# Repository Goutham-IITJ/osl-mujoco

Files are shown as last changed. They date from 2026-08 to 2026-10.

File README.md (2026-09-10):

# OSL V2 in MuJoCo

A physics model of the Open-Source Leg V2 (Neurobionics / University of Michigan),
built directly from the official Onshape CAD export and driven from plain Python.
No ROS, no Gazebo, no placeholder geometry.

The point of this repository is to have a trustworthy digital twin *before* the
real hardware is touched, so that motor control, IMU processing and gait-phase
estimation can be developed and broken safely.

Two things live here. The **model** — built from CAD, described from *What you get*
onward — and the **bench experiment**, which drives that model's knee along a real
human's knee-angle trajectory with a PD controller and measures how well it follows.
Start with the experiment; `docs/CODE_MAP.md` is one page and tells you where every
piece of it is.

## Quick Start

Windows PowerShell, from a clean machine. Everything below is run from the repository
root.

**1. Create the two environments.** The bench experiment needs two, and they are
deliberately kept apart — see the table below for why.

```powershell
# the simulation environment: MuJoCo, no plotting
py -3.10 -m venv .venv
.\.venv\Scripts\python.exe -m pip install --upgrade pip
.\.venv\Scripts\python.exe -m pip install mujoco==3.12.0 numpy glfw PyOpenGL

# the analysis environment: plotting, no MuJoCo
py -3.12 -m venv .venv-analysis
.\.venv-analysis\Scripts\python.exe -m pip install --upgrade pip
.\.venv-analysis\Scripts\python.exe -m pip install numpy matplotlib scipy
```

**2. Check that the tests pass.** These need numpy only, so any Python will do, and they
run in under a second:

```powershell
.\.venv\Scripts\python.exe tests\run_tests.py
```

**3. Run the things.** In order of what is most worth seeing first:

```powershell
# the validated AB19 benchmark: 2410 steps, CSV + metrics + figures
.\.venv\Scripts\python.exe experiments\run_bench_ab19.py

# is the result still the validated one?  compares 21 columns + every metric
.\.venv\Scripts\python.exe experiments\verify_against_oracle.py

# the live demo: MuJoCo viewer + a live dashboard in the browser
.\.venv\Scripts\python.exe experiments\run_live_demo.py

# the gain sweep that chose kp = 600
.\.venv\Scripts\python.exe experiments\run_gain_sweep.py

# figures from an already-logged CSV -- this is the one that needs .venv-analysis
.\.venv-analysis\Scripts\python.exe experiments\plot_bench_results.py
```

`run_bench_ab19.py` also draws the figures itself if matplotlib happens to be importable;
in `.venv` it is not, so it writes the CSV, prints the report, and tells you to run
`plot_bench_results.py`. Use `--no-plot` to silence that.

**Where the output goes.** Everything lands under `build\`, which is gitignored:

| Path | Written by | Contents |
| --- | --- | --- |
| `build\bench_track_ab19\bench_track_ab19.csv` | `run_bench_ab19.py` | 2410 rows × 21 columns, one row per 0.5 ms step |
| `build\bench_track_ab19\bench_track_ab19_metrics.csv` | `run_bench_ab19.py` | the summary metrics and the 5 audit flags |
| `build\bench_track_ab19\bench_track_ab19.png` | `plot_bench_results.py` | the six-panel results figure |
| `build\bench_track_ab19\bench_track_ab19_human_reference.png` | `plot_bench_results.py` | the human reference figure |
| `build\gain_sweep\` | `run_gain_sweep.py` | the sweep trace and its metrics |
| `build\verify_oracle\` | `verify_against_oracle.py` | the fresh run it compares against the oracle |
| `tests\oracle\` | — | the frozen validated result. **Committed, not generated.** |

**Which environment do I need?** Four exist on this machine and only the first two belong
to this experiment:

| Environment | Python | Holds | Used for |
| --- | --- | --- | --- |
| `osl-mujoco\.venv` | 3.10 | mujoco 3.12.0, numpy, glfw, PyOpenGL — **no matplotlib** | everything that runs physics: the benchmark, the sweep, the live demo, the oracle check, the tests |
| `osl-mujoco\.venv-analysis` | 3.12 | numpy, matplotlib, scipy, h5py — **no mujoco** | offline figures only (`plot_bench_results.py`), and the dataset tooling |
| `myo_folder\.venv-myoassist` | — | MyoAssist + MyoSuite | *not this experiment.* The MyoAssist musculoskeletal work, which is paused. |
| `myo_folder\.venv-myoassist-ctrl` | — | MyoAssist reflex-controller stack | *not this experiment.* Same. |

The split is not tidiness. `.venv` is the environment the validated result was produced in
and it is left alone on purpose, so the physics cannot silently change underneath a
recorded number; matplotlib and scipy pull in a large dependency tree and neither is needed
to step MuJoCo. That is also why plotting is a separate offline entry point reading a CSV
rather than a call at the end of the simulation, and why the live dashboard is a browser
page rather than a matplotlib window.

**The bench experiment needs neither MyoAssist environment, and touches no MyoAssist file.**

## How the bench experiment works

```
   build/AB19_knee_gait_reference.csv
   real human gait data -- subject AB19, one right-leg cycle, 101 samples
                    |
                    v
   +--------------------------------------+
   |  REFERENCE PROCESSING                |   oslbench/reference.py
   |  validate columns, audit, cubic      |   101 samples -> 2410 steps
   |  spline resample onto dt = 0.5 ms    |
   +--------------------------------------+
                    |
                    v
              q_ref(t)   the commanded knee angle, in radians
                    |
                    v
   +--------------------------------------+
   |  PD CONTROLLER                       |   oslbench/controller.py:95
   |                                      |
   |    error = q_ref - q                 |   Kp = 600.0    N.m/rad
   |    tau   = Kp * error - Kd * qdot    |   Kd = 17.253   N.m.s/rad
   +--------------------------------------+
                    |
                    v
   +--------------------------------------+
   |  ACTUATOR SATURATION                 |   two separate clamps
   |  command -> ctrlrange  (the ROM)     |   knee ROM  [-5, 120] deg
   |  torque  -> forcerange (authority)   |   knee tau  +/- 142.2 N.m
   +--------------------------------------+
                    |
                    v
   +--------------------------------------+
   |  MuJoCo ACTUATOR                     |   models/osl_v2_bench.xml
   |  tau = Kp*(ctrl - q) - Kd*qdot,      |   position actuator on the
   |  clamped, applied to the knee hinge  |   knee joint
   +--------------------------------------+
                    |
                    v
   +--------------------------------------+
   |  MuJoCo PHYSICS STEP                 |   mj_step, every 0.5 ms
   |  I_eff = 0.261998 kg.m^2, gravity,   |   fixed base: the segment
   |  joint damping, joint friction       |   above the knee is welded
   +--------------------------------------+
                    |
                    v
              q(t)   the ACTUAL knee angle
                    |
      +-------------+-------------+-------------+
      |             |             |             |
      v             v             v             v
  tracking      actuator        joint       mechanical
   error         torque       velocity        power
 q_ref - q     tau (N.m)     qdot (rad/s)   tau * qdot
      |             |             |             |
      +-------------+------+------+-------------+
                           |
                           v
              +--------------------------+
              |  LOGGER                  |   oslbench/logging.py
              |  one row per step,       |   no physics in here
              |  21 columns              |
              +--------------------------+
                           |
        +------------------+------------------+
        |                  |                  |
        v                  v                  v
   bench_track        METRICS            PLOTS
   _ab19.csv          RMS / peak /       six-panel figure
   2410 rows          torque / lag       drawn AFTER the run
                   oslbench/metrics.py   oslbench/plotting.py
```

Nine things that flowchart is meant to make unambiguous, because each of them is a
question that has actually been asked:

1. **The reference is real human data.** It is not a synthetic sine wave and not an
   idealised curve. It is subject AB19 of the Camargo et al. lower-limb dataset, trial
   `levelground / ccw / normal / 01_01`, one right-leg cycle of 1.2050 s. The audit that
   runs on load prints five flags, and all five concern the dataset's *moment* and *power*
   columns, which are defective and are carried through unused; the angle column that
   drives the experiment is sound.

2. **The controller runs during the simulation.** `error = q_ref - q` and
   `tau = Kp*error - Kd*qdot` are evaluated inside the stepping loop, once per step, at
   2 kHz — using the angle and velocity MuJoCo reported on the previous step. It is not
   pre-computed, and there is no recorded torque being played back.

3. **MuJoCo physics runs every 0.5 ms.** 2410 steps for one gait cycle. That timestep is
   authored in `models/osl_v2_bench.xml` and the experiment reads it rather than assuming
   it; the tests fail if it changes.

4. **The controller is not plotting anything.** `oslbench/controller.py` imports no
   plotting library, writes no file and prints nothing. It is 154 lines and the control law
   is three of them.

5. **The simulation is not generating plots in real time.** `oslbench/simulation.py` has no
   figure in it. The only case where anything is drawn while the physics runs is the live
   demo, and there the drawing is a *consumer* of state that the simulation published — see
   point 7.

6. **The offline plots are generated after the simulation, from the logged CSV.**
   `experiments/plot_bench_results.py` reads `bench_track_ab19.csv` and draws figures. It
   never loads a model and never steps physics — which is why it runs in
   `.venv-analysis`, an environment that has no MuJoCo installed at all. That is a
   structural proof rather than a promise.

7. **The live dashboard is visualisation only and cannot affect the controller.** The
   browser page has no plant model and no controller in it; it polls the simulation loop
   about sixteen times a second for a snapshot of the one shared state and draws it on a
   canvas. Because it redraws in the browser's process it cannot slow the physics, and
   because it has nothing to integrate it cannot become a second simulation. Before the
   viewer opens, `oslbench/viewer.py:consistency_check` replays a span of the quantitative
   benchmark through the live code path and refuses to start unless angle, velocity, torque
   and command agree to 1e-12.

8. **The six-panel figure is generated from recorded simulation results.** Every point on
   it was read out of the CSV that a completed run wrote. It is not a live trace, not a
   sketch, and not measured on hardware.

9. **The physical hardware has not been validated.** Nothing here has been compared against
   the real Open-Source Leg. There is no encoder log, no bench torque measurement and no
   hardware trial. Every number in this repository is a simulation result, and
   `docs/BENCH_EXPERIMENT.md` lists specifically which parts of the model are placeholders.

The validated result, which `verify_against_oracle.py` re-checks column by column:

| RMS error | peak error | peak torque | saturation | peak velocity |
| --- | --- | --- | --- | --- |
| 4.3616° | 9.0907° | 16.0041 N·m (11.25 % of authority) | 0.00 % | 5.0559 rad/s |

90.1 % of that RMS error is a 29.5 ms servo phase lag: remove the shift and the error
falls to 0.4333°. The fix for a lag is feedforward or advancing the reference, not more
stiffness — which is why `kp` stays at 600.

`docs/BENCH_EXPERIMENT.md` is the long form of all of this, in question-and-answer form,
including what the torque is not (it is not a human knee moment) and what the sim-to-real
limitations are. `docs/LIVE_DEMO.md` covers the two-window demo, `docs/VALIDATION.md` the
proof that reorganising the code did not change the result, and
`BENCH_TUNING_AND_DATASET.md` where kp = 600 came from and where the AB19 data came from.

## What you get

Three scenes are generated into `models/`. `osl_v2_bench.xml` welds the leg to the
world, which is the configuration for testing controllers and watching the joints
move without worrying about balance. `osl_v2_ground.xml` gives it a free joint,
puts a floor underneath, and carries collision geometry — the Variflex blade at
the sole, plus one bounding box per module above the ankle — for stance and
loading. The bench and ground scenes both ship a `flat` keyframe that levels the
sole — which is *not* ankle = 0, see the flat-foot finding below — and in the
ground scene it also drops the leg onto the floor. Whether the ground scene stands
or topples has not been established — a single leg with no socket, hip or balance
controller is not obviously stable, though a static check suggests the COM does
project inside the sole footprint with margin. `check_model.py` prints the base
height before and after a second of settling, which answers it.

`osl_v2_walk.xml` is the Phase 2 scaffold: the same CAD device, now hung under a
minimal human model so it can be driven along a walking trajectory. A pelvis is
suspended over the floor — welded, because a prescribed trajectory will drive it
later and there is no balance controller — a residual thigh swings from it on a
`hip` hinge, a socket couples that thigh to the device through four *passive*,
spring-damped DOFs (a vertical piston plus flexion, ab/adduction and rotation —
the compliance a real socket–limb interface has), and the device bolts rigidly
beneath the socket. A second, lumped intact leg swings from the pelvis on its own
hip hinge so the model has two feet on the floor. It ships a `stand` keyframe with
the feet flat and the socket relaxed. Everything above the device — pelvis, thigh,
socket, intact leg — is an anthropometric **placeholder**: not CAD, not fitted,
sized from 50th-percentile tables and meant to be reconciled with the `myoOSL`
human later. See the note under *Simplifications*.

All three scenes carry the same CAD device — the three-body chain knee_prox, shank,
foot, with a knee hinge and an ankle hinge, position actuators on both, and a
sensor suite that mirrors what the real leg reports: joint encoders, actuator
torque, a knee_prox IMU, a shank IMU, and the six-axis load cell. The walk scene
adds hip and contralateral-hip actuators and reports the four passive socket DOFs
as joint-position sensors, so socket travel is observable.

```
python scripts/check_model.py                      # compile, CAD cross-check, contact
python scripts/view_osl.py                         # interactive viewer, bench
python scripts/view_osl.py --scene ground          # viewer with the floor
python scripts/view_osl.py --scene ground --flat   # standing, sole level
python scripts/view_osl.py --scene walk            # device on the walking scaffold
python scripts/view_osl.py --knee 60 --ankle -15   # start in a pose
python scripts/demo_sweep.py                       # sinusoidal knee/ankle sweep
python scripts/demo_sweep.py --headless --csv build/sweep.csv
```

In the viewer, `Tab` opens the control panel where the knee and ankle sliders
live and `space` pauses. The Group toggles hide geom groups: the visual meshes
are group 2, and group 3 is the collision geometry, which exists in the ground and
walk scenes — the blade mesh at the sole, plus the four bounding boxes that stop
the shank and knee_prox reaching the floor, and in the walk scene a box under the
intact foot. The bench scene has no collision geometry at all.

## Model summary

Masses and centres of mass, the latter in **world** coordinates at zero joint
angles (the MJCF stores them body-relative, so the XML numbers will not match
these directly; `check_model.py` prints the world values):

| | mass | COM, world (m) | parts kept | parts culled |
|---|---|---|---|---|
| knee_prox | 0.4498 kg | +0.0002, −0.0074, +0.1997 | 28 | 60 |
| shank | 3.5908 kg | +0.0047, +0.0028, +0.0320 | 142 | 347 |
| foot | 0.9152 kg | −0.0066, −0.0037, −0.1608 | 47 | 26 |
| **total** | **4.9558 kg** | | **217** | **433** |

80 distinct meshes, 1,310,462 triangles. The knee hinge sits at
`(0.00065, 0, 0.19311)` and the ankle at `(0, 0, −0.13873)`, 331.84 mm apart,
both taken from the CAD rather than chosen. Knee range −5° to +120° (positive is
flexion), ankle −30° to +20° (positive is dorsiflexion). Those ranges are from
this export's own hard stops and they differ slightly from the 0–120° and
±30° quoted for "the OSL v2" in Tan et al. 2025; the difference is kept, because
the CAD is the better authority on the specific leg being modelled. Worth
re-measuring on the hardware.

Coordinates are the export's own, so `z = 0` is a point mid-pylon and not a
landmark. The bench-scene bounding box is
`[−0.1665, −0.0437, −0.2302] .. [0.0846, 0.0752, 0.2602]`: 490 mm of build
height from the sole at z = −0.2302 to the top of the proximal pyramid at
z = +0.2602, and 119 mm across. The ankle axis is 91.5 mm above the sole. In the
ground scene everything is lifted so the floor is z = 0, which puts the ankle
axis 93.5 mm above the floor at zero joint angles — 91.5 mm of build height plus
2 mm of spawn clearance, nothing else. The blade really is the lowest thing in
the model (`model_min_z` and the sole's own lowest z are the same −0.2302), and
every bounding box bounds meshes that are already inside that minimum, so there
is no fudge term. The `flat` keyframe sits 3.8 mm lower, at a base height of
0.2284 m, because rotating the sole level tucks the toe up.

Anterior is **−X**, posterior **+X**, and the sagittal plane is XZ. This comes
from the Variflex blade, whose long forefoot runs from the mounting bolts at
x ≈ +0.035 out to x = −0.1665.

## Why the URDF could not simply be loaded

why there is a build step.

The Onshape export (`osl_v2_0_assembly/urdf/`, 682 links, 681 joints, 14,584
lines) has no materials assigned, so every `<inertial>` block is nonsense — the
whole leg weighs 14.75 grams in the file, and 52 of the 657 inertia tensors have
a non-positive eigenvalue (8 of those also violate the triangle inequality that
any real rigid body must satisfy). MuJoCo's URDF reader eigen-decomposes each
inertia tensor while *parsing*, which means `compiler inertiafromgeom="true"`
never gets a chance to help: the load fails before the option is applied.
Sanitising the URDF in place was rejected for the same reason it was tempting —
682 hand-audited blocks is not a reviewable diff.

So `tools/build_mjcf.py` reads the export and emits native MJCF instead. Mass
comes from the exact mesh volume (divergence theorem over each closed triangle
mesh) multiplied by a density assigned per part family, and inertia is computed
about each segment's own COM and then rotated to principal axes. The original
URDF is never modified; everything generated lands in `models/` and `build/`.

Four further things had to be got right, and each was initially got wrong.

**Mesh poses need `<visual><origin>` composed on top of the link pose.** 207 of
the 682 links carry a non-identity visual origin, the largest a 206 mm
translation on the Variflex foot, and ignoring them produces an assembly where
the knee and ankle modules interpenetrate. Folding the origin in reproduces the
export's own declared centre-of-mass positions to a 0.000 mm median and 0.002 mm
at the 90th percentile, against 10.150 mm at the 90th percentile and 158.5 mm at
worst without it; the assembled leg becomes 251 × 119 × 490 mm rather than
211 × 327 × 532 mm, and 327 mm of medio-lateral width on a device under 120 mm
wide is the giveaway. `build/verify/visorigin_AB.png` shows both, and
`tools/verify_visorigin.py` regenerates it.

**Rigid clusters straddling a joint go to the segment opposite the housing.**
The 618 `fixed` joints contract by union-find into clusters, 38 of which carry
geometry, and each is assigned to knee_prox, shank or foot. Nine of the 38 sit
concentric with a hinge axis, where a plain "above or below the joint" split
would be a coin flip. The resolution is mechanical: in a belt-driven actuator the
output pulley rotates *relative to* its housing, and both housings are
shank-fixed, so a cluster concentric with the knee axis belongs to knee_prox and
one concentric with the ankle axis belongs to the foot. That is a 20 mm radius
test in the sagittal plane, applied before the z-split.

**The Össur foot mate is fine.** An earlier pass concluded the mate was corrupt
and reconstructed the foot from anatomical constants; that was an artefact of the
missing visual origin. With the frames right, the foot's length axis is 89.73°
from the ankle axis and the sole is within 2.18° of level — a real build tilt,
deliberately preserved. `_check_foot()` re-verifies this on every build and warns
if it ever stops holding. **The model contains no invented geometry.**

**The floor needed more than a box under the sole, and the sole is not level at
ankle = 0.** The first ground scene put a single tilted box on the sole, fitted to
the blade's bounding box — so its lower face sat 4.6 mm *below* the blade mesh —
and gave nothing above the ankle any collision geometry at all. Commanding the
ankle therefore tipped the leg and the shank sank straight through the floor.
Both halves are fixed. The sole is now a `type="mesh"` geom on the blade itself,
which MuJoCo collides by its convex hull, so the toe spring and the heel roll-off
survive exactly and only the 14 mm arch is bridged — deliberately, since under
load the real blade flattens toward that chord. It shares the visual geom's pose
exactly, because the previous failure mode was the leg standing on something the
viewer does not draw. Above the ankle each module gets one axis-aligned bounding
box: `knee_prox_shell` 78 × 79 × 106 mm, `knee_module` 128 × 119 × 204 mm,
`mid_pylon` 66 × 102 × 69 mm and `ankle_module` 137 × 118 × 192 mm, respectively
21 %, 22 %, 11 % and 20 % full by the volume of the parts they contain. Those
fill fractions are printed so nobody mistakes a box for a shape claim.
Membership comes from the CAD's own named housings — the knee housings span
z = 0.047..0.239 and the ankle housings −0.185..−0.028, disjoint with a 75 mm gap
— rather than from a hand-picked threshold, and the eleven parts that fall
between them are exactly the ones you would name by hand: the pylon, the load
cell, the pyramid and six M5 bolts. Four boxes are enough, and that is checked by
code rather than asserted in a comment: `OslModel.sweep_clearance` walks a 26 × 26
grid of knee −5..120° against ankle −30..+20° and compares the lowest point of
every visual mesh against the lowest point that can actually collide. The answer
comes out twice. Over all 216 visual meshes the worst case is 5.9 mm of clearance;
over the 46 that no box contains — the foot's non-blade hardware, since the foot's
only collision geom is the blade mesh and a mesh bounds nothing — it is 23.6 mm,
at knee = −5°, ankle = −2°, where an M8 socket head hanging off the blade mount is
the binding part. The two differ because a part inside a box on its own body can
never rise above that box, so its clearance only measures how close a rotating box
corner passes to the part that defined it; the second figure is the one with
information in it. Either way no mesh can reach the floor before a collision geom
does. Both numbers are written into the sidecar and `check_model.py:sweep_test`
re-derives both from MuJoCo's own forward kinematics, finding the collidable geoms
by `contype`, the blade by mesh identity and the boxed parts by testing every
vertex in each box's frame, rather than reading any of it from the prediction — so
the CAD sweep and the MuJoCo sweep are two independent measurements of the same
pair of quantities. Both are affordable only because of one shortcut: since every
rotation here is about world Y, the lowest point of a rigid group is the minimum of
a linear functional on the sagittal plane and is therefore always attained at a
vertex of the group's convex hull projected to (x, z), which turns four screw
meshes of 193 k vertices each into a few dozen candidate points for all 676 poses
at once. That is an argument, not a sample, so `sweep_test` redoes each worst pose
with every vertex and fails if the reduced answer differs.
Capsules and z-slabs were both measured and rejected — PCA capsules wanted
r = 81 mm and len = 174 mm on a part whose bounding box is 128 × 119 × 204 mm and
still left 1.0 % of vertices 14.8 mm outside, and 25 mm z-slabs cost 23 geoms to
raise fill from 22 % to 30 %, because the looseness is in x and y where the
batteries hang off, not in z.

And the sole is 2.40° toe-down at ankle = 0, which is the other half of "the leg
falls over when I move the ankle". The dominant edge of the blade's lower convex
hull in the sagittal plane runs 149.5 mm at +2.3971°, from (−0.08936, −0.09146)
to (+0.06001, −0.08521) in the foot frame; the next-longest hull edge is only
34.7 mm, so the contact face is unambiguous by a factor of 4.3. Put the ankle at
+2.3971°, well inside the +20° limit, and the contact becomes a genuine
161 × 64 mm patch: 173 blade vertices within 2 mm of the lowest point, flat to
0.49 mm rms, with a residual tilt of +0.29° sagittal and under 0.01° frontal.
That the frontal residual is negligible is what makes this fixable at all, since
one ankle hinge could never have corrected a frontal tilt. The pose is the `flat`
keyframe in the bench and ground scenes; `view_osl.py --flat` loads it. `build_mjcf.py` derives the
standing height by rotating CAD meshes and `validate_mjcf.py` re-derives it by
rotating the *emitted XML's* collision points about the *emitted* ankle anchor, and
both land on the same +2.00 mm above the floor, which is the spawn clearance and
nothing more. The angle and the edge are still one derivation, though, and would
agree with each other for free — so `check_model.py:flat_test` loads the keyframe
and pushes both endpoints of that edge through MuJoCo's forward kinematics,
requiring them to come out level there too, along with the base height, the set of
collidable geom names and the 2.00 mm clearance itself.

## Simplifications, stated plainly

**Small parts are dropped.** Anything below 0.1 cm³ loses its geometry and has
its mass lumped into the parent segment: 433 of 650 parts, but only 52 g, or
1.05 % of the mass, because they are fasteners, washers and bearing races.
`build/mass_audit.csv` lists every part with its volume, assigned density, the
rule that assigned it, and whether it was kept, sorted by mass. Regenerate it
with `python tools/validate_mjcf.py --audit`.

**The densities are assignments by part family, not measurements.** Aluminium at
2700 covers 245 parts and is the default; steel at 7850 covers 240 fasteners,
bearings and the load cell; electronics at 1500 covers 133 parts of the
Raspberry Pi and its connectors; NdFeB magnets 7500; the Dephy BA30 packs and
the FR-4 PCB 1900; the Variflex blade 1550 as carbon fibre; belts and printed
covers 1250. `tools/cad_findings.py` prints the full usage table.

**The total is 0.42 kg light, and the missing motors account for it.** The model
comes out at 4.9558 kg against a published 5.377 kg for a real OSL V2 build
(Tan et al., *MyoAssist 0.1*, ICORR 2025, which cites Best et al. 2024 and
Azocar et al. 2018; Elliott Rouse, who runs the OSL project, is a co-author).
The reason is that **the Onshape export contains no motors.** All 260 distinct
meshes were searched: the only motor-related part is `p_b0004_motorCoupling.stl`
at 8.8 g, present twice — the couplings that bolt *to* the motors. There is no
rotor, no stator, no gearbox and no Dephy actuator body anywhere in the export.
The 0.4212 kg shortfall is 0.2106 kg per motor, which is the right order for a
brushless motor of this class.

That is a hypothesis, and the way to settle it is to put a motor on a scale.
`MOTOR_MASS` in `build_mjcf.py` will lump a measured per-motor mass at each
coupling centroid, and **it defaults to zero on purpose**: inferring the motor
mass from (published − ours) and then citing the resulting agreement as
validation would be circular. The 4.9558 kg figure has to stand on its own, so
the shipped model stays purely CAD-derived.

An earlier version of this file claimed the opposite — that the model was too
*heavy*, against a 3.0–4.5 kg range. That range was recollection with no source
behind it and it was wrong. `MASS_RANGE` is now 4.70–5.20 kg, the window the
CAD-only total should land in given two absent motors. It governs the **device**,
so in the walk scene the validator range-checks the device mass alone and ignores
the scaffold; by that measure all three scenes sit inside it.

**The walk scene's human scaffold is a placeholder, not a measurement.** The
pelvis (10 kg), residual thigh (3.5 kg, 0.20 m), socket (0.6 kg) and lumped intact
leg (~12 kg) are anthropometric round numbers — 50th-percentile segment masses and
lengths of the kind tabulated in Winter's *Biomechanics and Motor Control* — with
capsule and box geometry that carries `contype=0`, so none of it collides with
anything except through the box under the intact foot. The four socket DOFs have
hand-set stiffness and damping standing in for a socket–limb compliance that has
not been characterised. None of this is CAD and none of it is fitted: it exists so
the CAD device has a hip to hang from and two feet to stand on while a walking
trajectory is developed, and it is meant to be replaced by — or reconciled
against — the `myoOSL` musculoskeletal human in MyoAssist. The hip height is not
chosen but derived (unloaded leg length below a welded pelvis), so the device sole
sits 2 mm above the floor at the default pose, exactly as the ground scene lifts
the free leg.

**Everything inside the actuators is collapsed.** Belts, pulleys, gearboxes and
bearings contribute mass and geometry but no relative motion; the knee and ankle
are single hinges with lumped `armature`, `damping` and `frictionloss` standing
in for the transmission. Those numbers (armature 0.010 and 0.008 kg·m², damping
0.30 and 0.25 N·m·s, friction 0.40 and 0.30 N·m) are placeholders to be
identified from bench data, not derived quantities. Peak torque is *not* a
placeholder: the actuator `forcerange` is ±142.2 N·m at the knee and
±168.2 N·m at the ankle, the published figures from the same paper as the mass.
The position-servo gain `kp = 60` is a placeholder and a soft one — it will not
hold a limb under body weight and is expected to change as soon as the model is
loaded.

**Contact is faithful at the sole and coarse everywhere else.** The sole is the
blade's own mesh, collided by its convex hull, which is honest geometry. Above it
are four bounding boxes at roughly 20 % fill, whose only job is to keep the leg
out of the floor; any result that depends on *where* the shank or the knee touches
something is not yet meaningful. There is no self-collision model either —
MuJoCo's `filterparent` removes knee_prox↔shank and shank↔foot automatically, and
knee_prox↔foot was shown unreachable across the joint ranges rather than modelled.

**Contact timing is set, contact depth is measured rather than predicted.** Both
scenes now write `solref="0.002 1"` and `solimp="0.95 0.99 0.001 0.5 2"` instead
of inheriting the compiler defaults. The argument is about time, since that is
what `solref[0]` specifies: the default 0.02 s time constant is 40× the 0.5 ms
timestep and slower than the 10 ms scale on which heel strike, foot flat and toe
off resolve, so it would smear exactly the transitions an impedance controller
switches on. 0.002 s puts the contact an order of magnitude faster than the
control events, and is deliberately 4× the timestep rather than sitting on
MuJoCo's `timeconst >= 2 * timestep` stability floor. Resting penetration scales
as the square of that constant, so the change is worth about 100× — but the
absolute depth is **not** predicted anywhere in this repo, because the
coefficient depends on how the `solimp` impedance enters the solver's
regularisation and `check_model.py` can read `contact.dist` and simply measure
it. What is asserted is a bound: 0.5 mm, chosen against the 0.49 mm rms flatness
of the contact patch, past which the sole sinking starts to matter next to the
shape of the sole itself. One trap worth knowing, and the reason the floor plane
and the leg's collision geoms share a single `contact` default class: MuJoCo does
not take the stiffer of two touching geoms, it averages `solref` and `solimp`
between them, so a floor left at the default would have quietly given back most
of the benefit. `validate_mjcf.py` resolves the default-class chain of every
collidable geom and fails if they ever disagree.

## Layout

`tools/oslcad.py` is the geometry layer — STL reading, exact mesh mass
properties, the URDF graph, rigid-cluster contraction, density rules.
`tools/build_mjcf.py` turns that into the three MJCF scenes and is where every
measured constant lives. Alongside each scene it writes
`models/osl_v2_<scene>.pred.json`: the masses, world centres of mass, hinge
anchors and mesh bounding box it expects MuJoCo to report, so that
`check_model.py` can hold MuJoCo to the CAD instead of merely asking whether it
compiled.
`tools/validate_mjcf.py` re-implements MuJoCo's compile checks in pure Python so
the model can be verified without MuJoCo installed; all three scenes currently pass
clean — 1767, 1815 and 1979 checks with no warnings. It also independently re-derives
the `flat` keyframe from the emitted XML, because a keyframe whose whole purpose is
"stand the leg level on the floor" is exactly the kind of claim that can be
silently false — the sole geometry it replaced sat 4.6 mm below the mesh it was
meant to hug and nothing noticed.
`tools/cad_findings.py` re-derives every geometric claim with its evidence and is
what `docs/CAD_FINDINGS.md` contains.
`tools/softrender.py` is a dependency-free rasteriser; `tools/verify_visorigin.py`
and `tools/render_poses.py` use it to regenerate the two evidence images.
`render_poses.py` reads the *generated* MJCF and steps it through seven
knee/ankle poses, which catches the class of error a compile check cannot: a
segment on the wrong body, a flipped axis, a misplaced hinge.

`scripts/check_model.py`, `scripts/view_osl.py` and `scripts/demo_sweep.py` are
the three things you actually run, sharing `scripts/mjcommon.py`. `check_model.py`
is the only one that is a test: it compiles all three scenes, compares masses, centres
of mass, hinge anchors and mesh bounding boxes against the sidecar, reads the
resting contact depth off `contact.dist`, watches a second of settling, and
re-derives the collision sweep and the flat keyframe from MuJoCo's own kinematics.
It exits non-zero on any disagreement, so it is safe to put in front of anything
else. The other files in `scripts/`, plus `build/osl_v2_*.urdf`,
`osl_v2_first_sim.xml` and `run_osl_v2_first_sim.py`, are dead ends kept only for
the record: the URDF-sanitiser attempts and the early rods-and-capsules smoke test.
Neither is the simulation.

`oslbench/` is the bench experiment's library — the model loader, the PD controller,
the gait reference, the stepping loop, the logger, the metrics, the offline figures, and
the live viewer and dashboard, one job per module. `experiments/` holds the thin entry
points that call it and `tests/` the assert-based test suite. `docs/CODE_MAP.md` is a
one-page index of all of it, `docs/BENCH_EXPERIMENT.md` the long explanation, and
`docs/REFACTOR_MAP.md` the record of what the code looked like when it was two large
scripts instead.

To rebuild from the CAD:

```
python tools/build_mjcf.py --report      # regenerate models/
python tools/validate_mjcf.py --audit    # pre-flight + mass audit, no MuJoCo
python tools/cad_findings.py             # re-derive the constants + evidence
python tools/verify_visorigin.py         # regenerate the frame-convention proof
python tools/render_poses.py             # visual articulation check
python scripts/check_model.py            # real MuJoCo compile + CAD cross-check
```

Only the last step needs MuJoCo, and it is the one step that has never been run
here — the build environment has no MuJoCo and no network, so "would compile" is
a prediction from a re-implementation of the checks, not a result.

That gap matters more than it sounds, because every check above shares one
codebase and therefore one set of assumptions. The specific thing it cannot see:
MuJoCo recentres mesh vertices onto the mesh centroid when it compiles, and is
supposed to fold the same translation into the geom frame so the mesh still
lands where it was authored. If it did not, every visual geom would be displaced
by its own centroid offset — tens of millimetres here — and nothing in the pure
Python tooling would notice, because it shares the convention it is trying to
verify. `check_model.py` closes that by taking MuJoCo's *own* stored vertices
(`mesh_vert`, post-recentring), placing them with MuJoCo's *own* resolved geom
frames (`geom_xpos`/`geom_xmat`, post-compensation), and comparing the resulting
bounding box against the CAD prediction in the sidecar. Agreement to 0.1 mm
means the whole chain — visual origins, cluster assignment, body offsets, mesh
recentring — is consistent. Disagreement says which of them is not. The same is
true of the two kinematic tests added with the contact work: the sweep and the
flat keyframe are both written to be re-derived from MuJoCo's forward kinematics
rather than from the sidecar, but neither has been executed against real MuJoCo
from here. They have been exercised against a stub with the correct rotation
conventions, including their failure paths, which establishes that they would fire
— not that they pass.

## Not done yet

Gait-phase estimation, IMU filtering, and sim-to-real transfer. Joint control now has a
first result — the bench experiment above tracks a real human knee trajectory with a PD
servo — but that is a baseline, not a hardware controller: no feedforward, no impedance
law, no electrical motor model, and nothing compared against the real leg. Transmission
parameters and densities want identification against the real hardware. Contact above the
ankle is bounding boxes, so knee-on-ground and shank contact will resolve at about the
right height but not the right shape. The contact timing is set and the tests that
would measure its consequences are written, but nothing in `check_model.py` has
been run against real MuJoCo from here, so the resting penetration and the
settling behaviour are still unmeasured — that single command is the cheapest
outstanding thing anyone can do to this repo. The walk scene now supplies the hip,
residual thigh, four-DOF socket and intact leg the ground scene lacked, so the
device can hang from a pelvis and stand on two feet. But everything above the
device there is an unfitted anthropometric placeholder (see *Simplifications*): the
segment masses, and the socket's stiffness and damping, want identification against
real transfemoral data or reconciliation with the `myoOSL` human in MyoAssist
(Tan et al. 2025), which the scaffold is deliberately shaped to line up with rather
than diverge from. And nothing drives it yet — there is no prescribed pelvis
trajectory and no gait controller, so the walk scene can stand but not step.
Getting from a standing scaffold to a natural walking trajectory is the next block
of work.

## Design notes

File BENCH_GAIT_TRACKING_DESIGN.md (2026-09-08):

# Bench gait-tracking experiment — design and model choice

**Status: DESIGN ONLY. No code written, no model modified, nothing run.**
Written 2026-09-03. Every number tagged **[MEASURED]** was read directly out of the model
files named below. Numbers tagged **[COMPUTED]** are derived analytically from those authored
values (parallel-axis on the MJCF `<inertial>` blocks) and can be re-checked in MuJoCo.
Numbers tagged **[ESTIMATE]** or **[EXPECTED]** are *not* verified and are flagged as such
everywhere they appear.

Reference: Camargo J., Ramanathan A., Flanagan W., Young A. (2021). *A comprehensive,
open-source dataset of lower limb biomechanics in multiple conditions of stairs, ramps, and
level-ground ambulation and transitions.* Journal of Biomechanics 119, 110320.
doi:10.1016/j.jbiomech.2021.110320

---

## Part 0 — Answers in one paragraph

Use **our CAD-derived `osl-mujoco/models/osl_v2_bench.xml` as the PRIMARY model** and the
official `OpenSourceLeg_KA_L1` as a **secondary cross-check** built into a matching fixed-base
bench scene. The primary choice is not a quality judgement: the CAD bench is already a bench
(welded base, two joints, no contact, no human, no muscles), its `ctrl` input is already a
reference *angle* so trajectory tracking is the actuator's native semantics, and every
quantity the experiment must log already exists as an authored sensor. `KA_L1` has no bench
scene at all — it exists only composed into a 30-DOF musculoskeletal model with a reflex
controller and ground contact — and its `ctrl` input is motor-shaft torque, so tracking on it
requires writing an outer-loop controller first, which would mix "does the device follow the
trajectory" with "is my controller any good". The torque model is suitable for this
experiment, because the bench never approaches the torque ceiling (peak demand ≈ 33 N·m
against ±142 N·m of authority in *both* models). The mass/inertia difference does **not**
materially affect the comparison: about the knee axis the two models differ by **+3.9 % in
mass and −6.4 % in rotational inertia**, which is far smaller than the servo-gain choice. The
numerical dataset is **not** in the paper — it is on Mendeley Data in three DOI-ed parts, as
MATLAB tables with a **pre-computed 0–100 % gait-phase column**, so **no manual digitization
is necessary**. Recommended single subject: **AB19** (M, 1.70 m, 68.0 kg — the cohort's
median anthropometry), level-ground, self-selected **normal** speed.

There is **one decision I cannot make for you** before code: the bench knee servo is authored
at `kp = 60 N·m/rad` with **no** velocity gain, which will produce roughly **32° of tracking
error at peak swing flexion** for reasons that have nothing to do with the device. See
Part 4 — that is a physics/control assumption and needs your approval.

---

## Part 1 — Model choice

### 1.1 What was measured in each model

Read from `osl-mujoco/models/osl_v2_bench.xml` (357 lines, generated by `tools/build_mjcf.py`
from the untouched Onshape export) — **[MEASURED]**:

| Property | Value |
|---|---|
| Base | root body `knee_prox` has **no** free joint → welded to the world. `bench_mount` site at z = 0.260203 m |
| Integrator / timestep | `implicitfast`, `timestep = 0.0005 s` (2 kHz) |
| Knee joint | hinge, axis `(0, −1, 0)`, range `[−0.0872665, 2.0943951]` rad = **[−5.00°, +120.00°]** |
| Knee joint dynamics | `damping = 0.3`, `armature = 0.01`, `frictionloss = 0.4` (authored, provisional) |
| Ankle joint | hinge, axis `(0, +1, 0)`, range `[−0.5235988, 0.3490659]` rad = **[−30.00°, +20.00°]** |
| Ankle joint dynamics | `damping = 0.25`, `armature = 0.008`, `frictionloss = 0.3` |
| Knee actuator | `<position name="knee_pos" kp="60.0" ctrlrange="−0.0872665 2.0943951" forcerange="−142.2 142.2"/>` — **no `kv`** |
| Ankle actuator | `<position name="ankle_pos" kp="60.0" ctrlrange="−0.5235988 0.3490659" forcerange="−168.2 168.2"/>` — **no `kv`** |
| Body masses | `knee_prox` 0.449846, `shank` 3.590758, `foot` 0.915159 → **4.955763 kg** total |
| Sensors already authored | `knee_q` (jointpos), `knee_qd` (jointvel), `knee_tau` (**actuatorfrc**), `ankle_q`, `ankle_qd`, `ankle_tau`, two IMUs (framequat + gyro + accelerometer at `imu_knee_prox` and `imu_shank`), and a 6-axis `loadcell` (force + torque) |
| Keyframe | `flat`: `qpos = (0, 0.0418372)`, `ctrl` identical |

Read from `myo_folder/assist_sim/assist_sim/models/OpenSourceLeg/KA_L1model.xml` and
`KA_L1config.yaml` — **[MEASURED]**:

| Property | Value |
|---|---|
| Base | root body `osl_generic_socket` is also welded to the world *in the standalone file*; in the approved scene it is attached to `femur_r` |
| Knee joint | `osl_knee_angle_r`, axis `(0, 0, −1)`, range `[0, 2.0944]` rad = **[0.00°, +120.00°]** |
| Ankle joint | `osl_ankle_angle_r`, axis `(0, 0, +1)`, range `[−0.5236, +0.5236]` rad = **±30.00°** |
| Joint dynamics | **none authored** → `armature = damping = frictionloss = 0` in the approved `myolegs22` scene (consistent with the earlier measured ideal-hinge finding) |
| Actuators | not in the MJCF — added from the YAML at compose time: `motor`, `gainprm 49.4` (knee) / `58.4` (ankle), `ctrlrange ±2.88`, `gear 1`, `ctrllimited` |
| Sensors | **none in the device MJCF**; only two `touch` sensors, added from the YAML |
| Body masses | socket 0.849991, femoral pylon 0.022058, proximal adapter 0.167000, knee assembly 2.245500, tibial pylon 0.062925, ankle assembly 1.739000, foot 0.291000 → **5.377474 kg** total, **4.527483 kg** excluding the socket |

Both models use the **same sign convention**, which I re-derived from the authored axes and
body offsets: **+knee `qpos` = flexion** and **+ankle `qpos` = dorsiflexion** in each. That
means one reference trajectory can drive both without a sign flip, and it is consistent with
the previously measured convention. Verify it once at run time anyway (Part 3.5).

### 1.2 The quantity that actually decides this experiment

On a **fixed-base bench with no ground contact**, the knee actuator does not fight body
weight. It fights only

```
τ_knee  =  I_knee·α  +  m g d·sin θ  +  b·ω  +  τ_friction
```

so the only mass property that matters is the **knee-distal rotational inertia about the knee
axis**, and the only mass-derived static term is the knee-distal gravity moment. Total device
mass is close to irrelevant here. **[COMPUTED]** from the authored `<inertial>` blocks
(each `diaginertia` rotated by its `iquat`, then parallel-axis shifted to the joint, ankle
held at 0):

| About the **knee** axis | CAD bench (ours) | `KA_L1` (official) | Δ (ours vs theirs) |
|---|---|---|---|
| knee-distal mass | 4.5059 kg | 4.3384 kg | **+3.9 %** |
| COM distance from axis | 0.20028 m | 0.19448 m | +3.0 % |
| **inertia about the axis** | **0.2520 kg·m²** | **0.2692 kg·m²** | **−6.4 %** |
| max gravity moment | 8.853 N·m | 8.277 N·m | +7.0 % |

| About the **ankle** axis | CAD bench (ours) | `KA_L1` (official) | Δ |
|---|---|---|---|
| ankle-distal (foot) mass | 0.9152 kg | 0.2910 kg | **+214 %** |
| COM distance from axis | 0.02303 m | 0.06904 m | −67 % |
| **inertia about the axis** | **0.00303 kg·m²** | **0.00276 kg·m²** | **+9.7 %** |
| max gravity moment | 0.207 N·m | 0.197 N·m | +4.9 % |

For context, the biological shank + foot this device replaces, for a 68.0 kg / 1.70 m subject
using Winter's anthropometric regressions — **[ESTIMATE], textbook regression, not measured**:
mass ≈ 4.148 kg, COM ≈ 0.2528 m from the knee, inertia about the knee ≈ **0.399 kg·m²**,
gravity moment ≈ 10.29 N·m.

Two things follow, and both are worth reporting:

The **foot-mass discrepancy that is still unresolved as a modelling question is not material
to this experiment.** Our foot is 3.1× heavier than theirs, but its COM sits almost on the
ankle axis (23 mm) while theirs sits 69 mm out, so the ankle-referred inertia and gravity
moment agree to within 10 %. Do not present this as resolving the discrepancy — it does not.
It only means the discrepancy cannot drive the bench result.

Both device models carry roughly **35 % less rotational inertia about the knee than the
biological limb** they replace. The tracking task is therefore not artificially hard, and any
tracking error we report is a statement about control, not about an over-heavy device.

### 1.3 PRIMARY: our CAD-derived `osl_v2_bench.xml`

Seven concrete reasons, in descending order of weight:

It **is already a bench**. Welded base, two hinges, no contact geometry in the active set, no
human, no muscles, 2 kHz fixed timestep, fully deterministic. `KA_L1` has no bench scene; it
exists only inside the composed 30-DOF musculoskeletal model driven by the reflex controller.
Running a knee-tracking experiment there would require either building a new bench scene from
the device fragment (new work) or freezing the human, which changes the physics.

Its `ctrl` **is a reference angle in radians**. `τ = kp·(ctrl − q)` — trajectory tracking is
the actuator's native semantics, so the experiment measures the *device*. On `KA_L1`, `ctrl`
is motor-shaft torque, so we would have to author an outer-loop controller first and the
result would be inseparable from the quality of that controller.

**Every logged quantity the experiment needs already exists as an authored sensor**:
`knee_q`, `knee_qd`, `knee_tau` (actuatorfrc = actual delivered joint torque), plus the ankle
triple, two IMUs, and a 6-axis load cell. Nothing new has to be authored. `KA_L1`'s device
MJCF has no sensors at all.

Its mass and inertia are **CAD-derived from the real OSL V2 assembly**, so the tracking result
is a statement about the actual hardware's inertia — which is the scientific point of a bench
study.

Its **knee ROM contains the whole human reference**, including the small terminal-stance
hyperextension: ours is `[−5°, +120°]`, `KA_L1` is `[0°, +120°]`. A human normal-walking knee
reference that dips 1–3° below zero near terminal stance would be **clipped by a hard joint
stop on `KA_L1`** and would contaminate the tracking error there. Ours would not clip.

It has **explicit joint damping, armature and friction** (0.3 / 0.01 / 0.4 at the knee).
These are provisional placeholders, not hardware values, and must be labelled as such — but a
tracking experiment on `KA_L1`'s frictionless zero-armature ideal hinge would be *less*
physical, not more.

It **does not disturb the MyoAssist integration**, which is mid-flight (the Step 2 rerun is
still outstanding). The two lines of work stay independent.

### 1.4 SECONDARY cross-check: `OpenSourceLeg_KA_L1`

Purpose: answer exactly one question — *how much of the tracking error is attributable to the
device model rather than to the controller?* Build a fixed-base bench scene from
`KA_L1model.xml` plus the two YAML actuators via **mjSpec in Python** (the repo already uses
mjSpec for composition; this avoids adding files to the cloned official repo and avoids the
`meshdir` problem of a hand-written wrapper XML). Then drive it with **the same reference,
the same outer-loop gains, the same timestep, and the same logging**, changing only the device.

Given the 6.4 % inertia difference, the expected outcome is that the two curves nearly
overlap. That is a *useful* result: it converts "our model is different from the official one"
into "the difference is 6 % of the inertia and X° of tracking error", which is a defensible
sentence for your professor. This is **new work and needs your approval** before I write it.

### 1.5 Is the torque model suitable for this experiment?

**Yes — with one framing condition.**

The peak torque demand on the bench, at the fastest part of the human swing phase
(θ ≈ 60°, ω ≈ 6.5 rad/s, α ≈ 93 rad/s² — **[ESTIMATE]** from a 60° flexion excursion in
~0.15 s):

```
I·α        = 0.2520 × 93   = 23.4 N·m
m g d sinθ = 8.853 × 0.866 =  7.7 N·m
b·ω        = 0.3 × 6.5     =  2.0 N·m
friction   =                  0.4 N·m
                             ------
total                        ≈ 33.5 N·m   =  23.5 % of ±142.2 N·m
```

Every idealization that `KA_L1`'s torque model omits — torque-speed curve, current and voltage
limits, drive efficiency, thermal derating, backlash, transmission compliance, device-authored
rotor inertia, actuator bandwidth and latency — bites **near the authority limit or at high
shaft speed**. At 23.5 % of authority and ≤ 7 rad/s they are second-order. So the torque model
is adequate *for this experiment*.

The framing condition: report it as **"torque authority was never the limiting factor in this
experiment"**, not as "the device can do this". The bench result cannot be extrapolated to
stance loading, where the real device operates much closer to its limits. And the required
wording applies verbatim:

> `OpenSourceLeg_KA_L1` models gearbox-related torque authority via knee gain 49.4, ankle gain
> 58.4, and a ±2.88 motor-shaft-torque `ctrlrange`, giving ≈ ±142.27 N·m at the knee and
> ≈ ±168.19 N·m at the ankle. It does **not** model the motor as an electrical system, nor
> current, voltage, torque-speed curve, efficiency, thermal state, backlash, transmission
> compliance, device-authored rotor inertia, or actuator bandwidth/latency. **The model
> represents the available joint torque authority derived from the motor/gear relationship,
> but idealizes the torque production.** The values 49.4 / 58.4 / 30 A / 0.096 N·m/A are
> recoverable model-derivation values from repository history, **not** experimentally verified
> hardware values, unless a hardware datasheet confirms them.

Note our bench actuator's `forcerange` is `±142.2` / `±168.2` — deliberately matched to the
same gear-derived authority, rounded down. So **the two models have effectively the same
torque ceiling** and the ceiling is not what distinguishes them.

### 1.6 The one thing the bench cannot do — state this before your professor asks

A fixed-base bench with no ground contact **cannot reproduce stance kinetics**. The human knee
moment in early stance (≈ 0.4–0.6 N·m/kg, so ≈ 27–41 N·m for a 68 kg subject — **[ESTIMATE]**
from the literature; read the real value off the dataset) is dominated by the body weight
being carried through the limb. On the bench that load does not exist, so the simulated knee
torque in stance will be **near zero while the human knee moment is at its maximum**. That is
an artifact of the boundary condition, not a model error.

Consequence for the design: **the kinematic comparison is valid across the whole cycle; the
torque comparison is only meaningful in swing** (roughly 60–100 % gait cycle, plus pre-swing),
where the human knee moment is small and mostly inertial and gravitational, and where the
human shank+foot (≈ 4.15 kg **[ESTIMATE]**) and the OSL knee-distal mass (4.51 kg
**[MEASURED]**) are within 9 % of each other. Plot the human moment anyway, but shade
0–60 % and label it *not directly comparable — fixed base, no limb loading*.

---

## Part 2 — The paper and the dataset

### 2.1 Where the actual numerical dataset is

**It is not in the PDF.** I checked: 9 pages, PDF 1.7, unencrypted, text-extractable, and
**zero embedded file attachments** (`pdfdetach -list` → 0). The paper's own "Reference Data"
section gives the repository — **[MEASURED, quoted from the paper]**:

- Part 1/3 — `http://dx.doi.org/10.17632/fcgm3chfff.1`
- Part 2/3 — `http://dx.doi.org/10.17632/k9kvm5tn3f.1`
- Part 3/3 — `http://dx.doi.org/10.17632/jj3r5f9pnf.1`
- Also mirrored / linked from `http://www.epic.gatech.edu/opensource-biomechanics-camargo-et-al/`
- Elsevier supplementary material at `https://doi.org/10.1016/j.jbiomech.2021.110320`

One caution on Part 2: the DOI suffix was broken across a line in the typeset PDF as
`k9kvm5t-` / `n3f.1`. I read that as `k9kvm5tn3f`, but the hyphen could in principle be real.
Verify by resolving the DOI before assuming.

Structure, quoted from §2.2 — **[MEASURED]**: *"Data are stored as tables grouped by the
nested directory structure of subject/date/mode/sensor"*, and *"Signals corresponding to the
same trial can be aligned using a header column containing the time (seconds). This column is
present in all the tables."* The dataset also ships MATLAB demonstration scripts:
`PLOT_TRIAL.m` (dataset structure + raw trial plot), `STRIDES.m` (segment into strides),
`PLOT_STRIDES.m` (the gait profiles in the results section), and `RUN_OSIM.m` (reproduces the
inverse kinematics, inverse dynamics and joint power).

The tables are **MATLAB tables**, and this is the single biggest practical risk in the whole
plan: `scipy.io.loadmat` cannot read MATLAB `table` objects — they serialize as opaque MCOS
class data and come back as `MatlabOpaque`. **First-hour test:** download one `ik` file, run
`scipy.io.loadmat` on it, and look at what comes back. If it is opaque, you need a one-time
MATLAB or GNU Octave export to CSV (the dataset already ships `.m` scripts, so MATLAB is the
path of least resistance), or a v7.3/HDF5 read via `h5py`/`mat73` if the files happen to be
v7.3. Do this **before** anything else — it determines the whole data-ingest step.

Do that work in a **separate analysis environment**, not `.venv-myoassist-ctrl`, so the
MyoAssist venv stays exactly as verified.

### 2.2 Best single subject and condition

**Condition: `levelground`, self-selected NORMAL speed.** From §2 — **[MEASURED]** — each
subject walked 5 clockwise + 5 counter-clockwise circuits at each of three self-selected
speeds (slow / normal / fast), 30 circuits per subject. Cohort pelvis velocities were
slow 0.88 ± 0.19, **normal 1.17 ± 0.21**, fast 1.45 ± 0.27 m/s. This matches your professor's
"normal / level-ground walking" exactly.

**Subject: AB19** — M, age 19, **height 1.70 m, mass 68.0 kg** **[MEASURED, Table 1]**. The
cohort is 1.70 ± 0.07 m and 68.3 ± 10.83 kg, so AB19 sits essentially *on* the cohort centre
in both. That matters practically as well as rhetorically: the moments are published
mass-normalized (N·m/kg), so a subject at the cohort mean mass makes the conversion to
absolute N·m transparent and makes the single-subject result maximally representative
**without averaging subjects**, which your professor forbade.

Backups, in order: **AB27** (M, 21, 1.70 m, 68.0 kg — *identical* anthropometry to AB19 and an
independent subject, which makes it the ideal "is this subject-specific?" check), then **AB20**
(F, 21, 1.71 m, 68.0 kg — same anthropometry, different sex).

Note the subject IDs are **not** contiguous: the 22 subjects are AB06–AB21, AB23, AB24, AB25,
AB27, AB28, AB30. There is no AB22, AB26 or AB29 — do not go looking for them.

**Which stride:** §2 says GRF was recorded *"in all locomotion modes during certain
representative steps … and at least one steady-state step"*, and §2.1 says *"Gait cycles
without ground reaction force data were excluded from moment and power analyses."* So on
level-ground most strides have kinematics but only some have moments. Selection rule: filter
to right-leg strides in the **normal**-speed level-ground trials that have **non-null knee
moment**, drop any stride adjacent to a turn or to the start/stop of a circuit, and take a
steady-state straight-line stride from the middle of a circuit. Report the trial file and the
stride index explicitly. **Do not average strides** — but do plot the neighbouring strides
faintly behind the chosen one, so the reader can see the chosen stride is not an outlier.
That satisfies "one subject, one stride" while still showing it is representative.

Fallback if AB19's normal-speed level-ground kinetics coverage turns out to be too thin: the
**treadmill** mode has continuous GRF from the instrumented treadmill (28 speeds, 0.5–1.85 m/s
in 0.05 m/s steps, 30 s each), so pick the treadmill speed nearest AB19's own self-selected
normal speed. Label it clearly as a substitution — your professor asked for level-ground.

### 2.3 Exact variables to extract, and units

Sampling rates and processing, all **[MEASURED]** from §2:

| Signal | Rate | Filtering as published |
|---|---|---|
| Motion capture (32 markers, bilateral, Helen Hayes set) | 200 Hz | gap-filled, lowpass 6 Hz zero-lag Butterworth order 4 |
| Ground reaction force (Bertec) | 1000 Hz | lowpass 15 Hz zero-lag Butterworth order 10 |
| Goniometers (right hip / knee / ankle) | 1000 Hz | lowpass 20 Hz Butterworth order 4 |
| IMU (torso, thigh, shank, foot — right) | 200 Hz | lowpass 100 Hz Butterworth order 6 |
| EMG (11 right-leg muscles) | 1000 Hz | bandpass 20–400 Hz Butterworth order 20 |
| Inverse kinematics / inverse dynamics / joint power | derived from the 200 Hz mocap via OpenSim | — |

Units, **[MEASURED]** from §3 and the Fig. 4 caption: joint angle in **degrees**, joint moment
in **N·m/kg**, joint power in **W/kg**. §2.3 states explicitly that *"the joint moments and
powers are normalized by the subject mass"* — so **absolute N·m = published value × 68.0 kg**
for AB19. GRF is in newtons. Time is in **seconds** in the first column of every table.

What to pull:

| Purpose | Variable | Unit | Notes |
|---|---|---|---|
| **The reference trajectory** | right knee sagittal angle from the `ik` output | deg → convert to rad | this is the one signal the experiment is built on |
| **The kinetic reference** | right knee sagittal moment from the `id` output | N·m/kg → ×68.0 → N·m | swing-phase comparison only, see §1.6 |
| Energetic context | right knee joint power | W/kg → ×68.0 → W | optional |
| Stance/swing segmentation | vertical GRF, right side | N | gives toe-off; expect ≈ 60–62 % GC |
| Ankle context / optional second DOF | right ankle sagittal angle and moment | deg, N·m/kg | primary run holds the ankle fixed |
| Residual-limb context | right hip flexion angle | deg | not used on the bench; useful later |
| Independent kinematic check | right knee **goniometer** sagittal angle | deg, 1000 Hz | a genuinely independent measurement of the same joint — cheap and valuable validation of the `ik` signal |
| Cycle normalization | the pre-computed gait-phase column | % | see §2.4 |

**Column names: [EXPECTED, NOT VERIFIED].** The dataset was processed with OpenSim, so the
`ik` columns are almost certainly OpenSim coordinate names (`hip_flexion_r`, `knee_angle_r`,
`ankle_angle_r`, …) and the `id` columns the same with a `_moment` suffix
(`knee_angle_r_moment`). I could not verify this — the sandbox has no network access and the
paper does not print the column names. **Verify by printing the column headers of one `ik`
file and one `id` file before writing any extraction code.** Five minutes there saves a
rewrite.

### 2.4 How to get one 0–100 % gait cycle

**The dataset already did this for you.** §2.2, verbatim — **[MEASURED]**:

> *"The gait phase of each data point was also calculated using linear interpolation between
> heel strikes from 0 % to 100 % gait cycle. Heel strike was determined from the motion capture
> data as the point of zero linear velocity of the heel marker."*

So there is no event detection to write and no heuristic to defend. Procedure:

1. Load the chosen trial's `ik` (and `id`) table plus the gait-phase / stride information.
2. Select **one right-leg stride** by the rule in §2.2 (normal speed, level-ground, has
   moments, steady-state, mid-circuit).
3. Record the stride's **measured duration** from the heel-strike timestamps. At ~1.17 m/s
   expect ≈ 1.0–1.2 s, i.e. **≈ 200–240 samples at 200 Hz** — **[ESTIMATE]**. This duration
   becomes the sim time base; do not substitute a nominal 1.0 s.
4. Resample to a 0–100 % phase grid at **0.5 % (201 points)** with a monotone interpolant
   (PCHIP) rather than a natural cubic spline, so the resample cannot overshoot at the sharp
   terminal-swing extension.
5. For the 2 kHz sim, interpolate the reference **in time**, and obtain the reference
   *velocity* analytically from the interpolant. Do **not** finite-difference a 201-point
   phase resample and then rescale — that amplifies resampling noise into the derivative term.
6. Repeat the cycle **≥ 5 times** back to back so the servo reaches a steady periodic state.
   Analyse the **last 3 cycles** and discard the transient. Report that you did.

### 2.5 Is manual digitization necessary?

**No, and it would be wrong here.** The numerical data are published, so digitizing is
unnecessary. More importantly, the curves in the paper's figures (Fig. 4 treadmill, Fig. 6
level-ground, Fig. 7 ramp, Fig. 8 stairs) are explicitly **22-subject averages** — §3:
*"reporting the 22 subject average profile for each condition within the mode"* — which is
precisely what your professor told you not to use. Digitizing Fig. 6 would violate the
"one subject, do not average" instruction. Use the repository.

---

## Part 3 — Recommended experiment design

### 3.1 One-line statement of the experiment

*Drive the knee of the fixed-base CAD-derived OSL V2 bench model with one able-bodied
subject's measured level-ground normal-walking knee-angle trajectory, and quantify how well
the modelled device follows it and at what torque cost, as a function of gait phase.*

### 3.2 Configuration

- Model: `osl-mujoco/models/osl_v2_bench.xml`, **unmodified on disk**.
- Timestep 0.0005 s as authored; control updated every physics step (2 kHz), which is far
  above the ~5 Hz content of the reference.
- Initial state: keyframe `flat`, then a short settle, then the reference starts at 0 % GC.
- Ankle: **held at its keyframe value (0.0418 rad)** for the primary run, so the knee is the
  only driven DOF and the result has one independent variable. A second run driving both
  knee and ankle is a natural follow-up.
- Gravity as authored (−9.81 ẑ). The bench hangs the shank downward from a welded mount, so
  gravity genuinely loads the knee — this is the right boundary condition for the experiment.

### 3.3 How to drive it without touching the model file

The `position` actuator's `ctrl` **is** the reference angle in radians, so the primary loop is
one line: `data.ctrl[knee] = ref(t)`.

The servo gains should be an **explicit, logged experimental parameter**, set at run time on
the compiled model rather than edited into the XML:

```
model.actuator_gainprm[knee, 0] = kp
model.actuator_biasprm[knee, 1] = -kp
model.actuator_biasprm[knee, 2] = -kv        # τ = kp(ref − q) − kv·q̇
```

This keeps `osl-mujoco` byte-identical on disk, makes the gains reproducible from the CSV
header, and lets the as-authored `kp = 60, kv = 0` be *one point in a sweep* rather than a
silent assumption. `forcerange = ±142.2` still clamps the output, so the gear-derived torque
authority is still enforced — which is what we want.

### 3.4 What to log (one row per control step, decimated for the CSV)

`time_s`, `cycle_index`, `gait_phase_pct`, `knee_ref_rad`, `knee_ref_deg`, `knee_sim_rad`,
`knee_sim_deg`, `knee_error_deg`, `knee_ref_vel_rad_s`, `knee_sim_vel_rad_s`,
`knee_ctrl_rad` (the actuator command), `knee_tau_Nm` (from the `knee_tau` actuatorfrc
sensor — the **actual delivered** joint torque), `knee_tau_frac_of_authority`,
`knee_saturated` (flag), `ankle_q_rad`, `ankle_tau_Nm`, `human_knee_moment_Nm_per_kg`,
`human_knee_moment_Nm`, and the run constants `kp`, `kv`, `subject_id`, `trial_id`,
`stride_index`, `stride_duration_s`, `subject_mass_kg` in the header.

That covers all five quantities your professor named — reference angle, simulated angle,
tracking error, actuator command, actual knee torque — plus the saturation and authority
columns needed to defend §1.5.

### 3.5 Validation gates — run these before trusting any plot

**Reference sanity.** A normal-speed able-bodied knee trajectory should show, approximately
**[ESTIMATE, textbook landmarks]**: ~0–5° flexion at 0 % GC; a stance-flexion peak of ~15–20°
near 15 % GC; near-extension ~0–5° near 40 %; toe-off near 60–62 %; a **peak swing flexion of
~60–65° near 70–73 %**; and a return to ~0–5° at 100 %. If the extracted signal is inverted or
offset, fix the sign/offset **and record the fix in the report** — OpenSim's `knee_angle_r`
convention is not universally flexion-positive, so this is a real possibility, not a
formality.

**Independent check.** Overlay the right-knee **goniometer** signal for the same stride. Two
independent instruments agreeing is much stronger evidence than one pipeline being
self-consistent.

**Sign check in the model.** Confirm in MuJoCo that +`knee` qpos is flexion by nudging `qpos`
and reading the distal body's Cartesian position — do not infer it from the torque, which is
circular. (My derivation from the authored axis says it is, for both models, but measure it.)

**Reference within ROM.** Assert the whole reference lies inside `[−5°, +120°]`. Log any
clipping. This is the gate that would have failed on `KA_L1`'s `[0°, 120°]`.

**Determinism.** Run the same configuration twice and assert bit-identical output.

**Energy/torque plausibility.** Assert peak `|knee_tau|` is in the tens of N·m, not hundreds.
If it saturates at 142.2 in steady state, the gains are wrong, not the device.

### 3.6 Metrics and plots

Metrics over the last 3 cycles: RMS error (deg), peak absolute error (deg) **and the gait
phase where it occurs**, phase lag (cross-correlation lag, in % GC), peak `|τ|` (N·m) and as a
% of authority, saturated fraction of the cycle, and the error decomposed into
**stance (0–60 %) vs swing (60–100 %)** — those two regimes fail for different reasons and a
single RMS number hides that.

Plots, all against % gait cycle: (1) reference vs simulated knee angle with the error shaded;
(2) tracking error; (3) commanded reference vs delivered torque, with the ±142.2 authority
lines drawn and the human knee moment on a second axis, **with 0–60 % shaded and labelled not
directly comparable** per §1.6; (4) RMS error vs `kp` for the gain sweep; (5) the same
overlay for the secondary `KA_L1` bench, once approved.

---

## Part 4 — Decisions I need from you before writing code

### 4.1 The servo gain — this is the one that will make or break the experiment

The bench knee actuator is authored at **`kp = 60 N·m/rad` with no velocity gain**
**[MEASURED]**. That was a reasonable placeholder for a static model; it is **not** adequate
to track a 1.1 s human knee trajectory. With `τ = kp·(ref − q)` and no feedforward, the
steady-state and dynamic error is `τ_required / kp` — **[COMPUTED]**:

| Operating point (θ, ω, α) | required τ | error at `kp = 60` | error at `kp = 600` |
|---|---|---|---|
| 15°, 1.0 rad/s, 20 rad/s² (early stance) | 8.0 N·m | **7.7°** | 0.8° |
| 35°, 7.0 rad/s, 60 rad/s² (pre-swing) | 22.7 N·m | **21.7°** | 2.2° |
| 60°, 6.5 rad/s, 93 rad/s² (peak swing) | 33.5 N·m | **31.9°** | 3.2° |

Also, the closed-loop natural frequency at `kp = 60` is
`√(kp/I) = √(60/0.252) = 15.4 rad/s = 2.46 Hz` — **below the bandwidth of the reference
itself** (fundamental 0.9 Hz, meaningful content to ~5–6 Hz). And with the authored joint
damping of only 0.3 N·m·s/rad against a critical value of `2√(kp·I) = 7.8`, the servo is
essentially undamped (ζ ≈ 0.04) and will ring.

So: as authored, the experiment would report ~30° of tracking error caused entirely by an
untuned placeholder gain, and any reviewer would say so immediately.

I see two legitimate framings and I recommend running **both**, because together they are a
much stronger result than either alone:

**(A) Tracking-capability framing (the headline).** Choose gains for good tracking and report
them explicitly as a *control choice*, not a device property. A defensible setting is
`kp = 600 N·m/rad` with `kv` set for ζ ≈ 0.7, i.e.
`kv = 2·0.7·√(kp·I) = 2·0.7·√(600 × 0.252) ≈ 17.2`, minus the 0.3 already in the joint, so
`kv ≈ 16.9 N·m·s/rad`. Natural frequency 7.8 Hz, comfortably above the reference. Expected RMS
error a few degrees. This answers your professor's literal request.

**(B) Impedance-realism framing (the second condition).** Hold `kp` at device-plausible
impedance values (the OSL literature uses knee stiffness of order 100–300 N·m/rad in stance)
and report the resulting error honestly. The finding — that a fixed-impedance law at
physically plausible stiffness *cannot* reproduce human knee kinematics without a
phase-scheduled reference — is exactly the known result that motivates finite-state impedance
control on the real OSL. This is a genuinely interesting sentence for your report rather than
a failure.

Concretely I propose a **gain sweep**: `kp ∈ {60 (as authored), 200, 600, 2000}` with matched
ζ = 0.7 `kv` at each, which on a 2-DOF fixed-base model at 2 kHz costs seconds of compute and
turns one number into a curve.

**Because this introduces a control/physics assumption, I am stopping here rather than
choosing for you.** Options, in the order I'd rank them: (i) the sweep above; (ii) `kp = 600`,
`kv ≈ 16.9` only; (iii) leave `kp = 60, kv = 0` exactly as authored and report the large error
as the honest result of the model as it stands.

### 4.2 Smaller decisions

**Where the extraction/experiment code should live.** The bench model is in `osl-mujoco`, and
this experiment is about that model, so `osl-mujoco/experiments/` is the natural home — but
your standing rule has been to keep `osl-mujoco` untouched. This document is the only thing I
have written there. Confirm the location before I add code.

**Whether to build the `KA_L1` secondary bench** (§1.4). It is new work: an mjSpec script in
`myo_folder`, not a file added to the cloned official repo.

**Whether to drive the ankle too**, or hold it fixed as recommended in §3.2.

**Whether to add the goniometer overlay** (§3.5). It is nearly free once the data are loaded
and it is the strongest independent validation available.

---

## Part 5 — Required wording for the CAD-vs-`KA_L1` comparison

Reproduced so it is quoted correctly in any write-up of this experiment:

> Neither model is simply "better"; they are intended to represent different things. **Ours**
> is an independent mechanical/device-only model with CAD-derived mass and inertia, CAD hard
> stops, explicit-but-placeholder joint and actuator dynamics, and a **position servo**.
> **`KA_L1`** is the official device fragment for human–device walking, with a direct torque
> actuator, gear-derived torque authority, composition onto the residual femur, device-aware
> keyframes, and reflex-compatible foot sensors.
>
> The often-quoted total mass difference is **not** enough to claim superiority. The official
> total of 5.377 kg includes an 0.85 kg socket. Like-for-like, excluding the socket, ours is
> ≈ 4.9558 kg against ≈ 4.5275 kg, so **ours is ≈ 0.4283 kg heavier**, and our foot is much
> heavier (0.9152 vs 0.2910 kg). **The source of the foot discrepancy is currently
> unresolved.** Do not change mass values merely to force the totals to match.

For this experiment specifically, add — **[COMPUTED]**, and it is the number that actually
matters here: about the knee axis the two models differ by **+3.9 % in knee-distal mass and
−6.4 % in rotational inertia**, and about the ankle axis by **+9.7 % in inertia** despite the
3.1× foot-mass difference, because our heavier foot carries its centre of mass much closer to
the ankle axis. The unresolved foot discrepancy therefore **cannot** be the dominant term in
the bench result. It remains unresolved as a modelling question.

---

## Appendix — Provenance

- Paper read via `pdftotext -layout` on the attached PDF (9 pages, 432 extracted lines).
  Verified with `pdfinfo` / `pdffonts` / `pdfdetach -list`: text layer present, fonts
  embedded, **0 embedded attachments**.
- Model facts read directly from `osl-mujoco/models/osl_v2_bench.xml` and
  `myo_folder/assist_sim/assist_sim/models/OpenSourceLeg/{KA_L1model.xml, KA_L1config.yaml}`.
- Inertia figures computed by rotating each authored `diaginertia` by its `iquat` and applying
  the parallel-axis theorem to the relevant joint origin, with the distal joint at zero.
  Re-checkable in MuJoCo via `mj_fullM` / body composite inertia.
- Biological shank+foot figures are Winter anthropometric regressions for 68.0 kg / 1.70 m
  and are **estimates**, included only for scale.
- **No model file, no code file, and no MyoAssist file was modified. Nothing was executed.**

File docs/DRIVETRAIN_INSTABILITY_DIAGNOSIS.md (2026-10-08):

# Why Case B diverged — diagnosis of the Option-C drivetrain instability

**Status: this was a DIAGNOSIS-ONLY document, and it has since been acted on.** As
written, nothing here was fixed; the collocation change it recommends in section 11 has
since been made in `oslbench/drivetrain_sim.py`. `Kp = 600` and `Kd = 17.253` are
unchanged and have **not** been retuned. Sections 1 and the appendix describe the code
**as it stood when the instability was diagnosed** — that is deliberate, because the
diagnosis is only legible against the code that produced the failure. Where a section
describes something that has since changed, it says so inline (see section 4).

What this work added: `experiments/diagnose_drivetrain_instability.py`, this document, and
the CSV/Markdown output under `build/drivetrain_instability/`. Nothing else was written.
`oslbench/controller.py` and `models/osl_v2_bench.xml` are tracked in git and
`git diff --ignore-cr-at-eol` is empty for both — those two are *attested* unchanged.
`oslbench/drivetrain.py`, `oslbench/drivetrain_sim.py`,
`experiments/run_bench_ab19_drivetrain.py` and `tests/test_drivetrain.py` are still
untracked (`??`), so git cannot attest to them; their unchanged state rests on mtimes,
all of which predate this work (2026-09-27 and 2026-10-03). `tests/oracle/*` shows a
whole-file diff that is **CR/LF only** — zero content change — and the AB19 reference CSV
is clean. One further file, `tests/stub_mujoco.py`, carries a +9-line working-tree change
(it gained a `qfrc_applied` array so the stub reproduces MuJoCo's raw-dof-force path);
that change is dated 2026-10-03_17:17, i.e. it belongs to the Option-C integration, not to
this diagnosis, and `stub_mujoco` is a test double, not a production file.

**This is a simulation result. It is not a hardware claim.** Nothing below says the
physical Open-Source Leg is unstable, would be unstable, or has ever been run with this
controller. Every statement is about the behaviour of *our* model of *their* drivetrain
under *our* bench controller.

The failure being diagnosed, as reported from the real-MuJoCo run:

| | Case A (position servo, drivetrain OFF) | Case B (drivetrain ON) |
|---|---|---|
| RMS tracking error | 4.3616 deg | — |
| peak joint torque | 16.0041 N·m | — |
| outcome | completes the gait cycle | **diverges at t = 0.6560 s** |
| engine complaint | none | NaN / Inf / huge QACC at DOF 0, then the belt-energy term overflows |

That blow-up time is not only a verbal report. `MUJOCO_LOG.TXT` in the repository root
holds MuJoCo's own line from that run, and it is the only real-engine artefact this
document rests on:

```
WARNING Sun Oct  4 07:55:30 2026: Nan, Inf or huge value in QACC at DOF 0.
The simulation is unstable. Time = 0.6560.
```

---

## 1. The cause

**The derivative term of the knee controller is non-collocated with the actuator it
drives, and across a compliant belt that term injects energy instead of removing it.**

Concretely: `PDCurrentSource` computed, **at the time of the diagnosis** (the code at
that line now reads the actuator side — see section 4):

```
tau_req = Kp*(clip(theta_ref) - theta_j) - Kd*theta_j_dot   # JOINT position AND JOINT velocity
I_q     = tau_req / k_t_joint
```

(the `clip` is `PDController.command`, `oslbench/controller.py:95-98`, which clips the
reference into `ctrlrange`; it is irrelevant to the stability argument but the law is not
quite the textbook one and the difference should not be hidden.)

and that current is applied to the **actuator shaft**, on the far side of the belt. The
joint never receives the motor torque directly; it only ever feels `tau_j`, the belt
torque. So `-Kd*theta_j_dot` is a force applied at one body, proportional to the velocity
of a *different* body, with a spring between them.

In the belt mode the two inertias swing in **antiphase against the spring**. In that mode
`theta_j_dot` and `theta_a_dot/n_t` have opposite signs, so a torque proportional to
`-theta_j_dot` applied on the actuator points *along* the actuator's own motion. It does
positive work on the mode every cycle. The mode grows; the belt hardens as it grows,
which raises the mode frequency but does not stop the growth; `|theta_s|` leaves the
range Best et al. actually fitted; the torque the belt law then reports is extrapolation;
and eventually MuJoCo's integrator is handed an acceleration it cannot represent and
raises `mjWARN_BADQACC` at DOF 0 — the knee.

**The divergence is therefore downstream of a feedback-architecture defect, not the
defect itself.** The NaN is the last symptom, not the cause. Section 7 sets out the
energy/power test that would make the instability measurable long before any number
overflows, and the real-MuJoCo run in section 7 shows it did.

This is not a surprise in hindsight, and that is worth saying plainly:
`docs/ACTUATOR_DYNAMICS_ANALYSIS.md:558-563` already recorded that Best et al. feed back
the **actuator's** states, and that using joint states instead is the non-collocated
configuration the paper avoids — adding that this was "invisible in our model, because
our model has no series elasticity for it to be non-collocated across."
`docs/DRIVETRAIN_INTEGRATION_OPTIONS.md` scored *"actuator state available to the
controller"* as a selection criterion for both Option B (line 120) and Option C (line
140). To be accurate about our own record: it was **not** among the four reasons actually
given for choosing C (lines 162-180 — protected files untouched, `nq = 2` keeps the oracle
alive, B's advantage evaporates, reversibility). So the capability was recognised and
scored; it was simply never used. The belt is now that series elasticity, and the
controller was never rewired to the actuator side. The instability is the bill for that.

### Why `Kd` and not `Kp`

`Kp` acts on `theta_j`, a *position*, and a position-proportional torque across a spring
is a stiffness, not a power source — it can detune the mode but it cannot pump it.
`Kd` acts on a *velocity*, and velocity feedback is exactly the term that sets whether
energy flows in or out. The analytic model in section 2 and the controlled comparison in
section 4 both isolate `Kd`.

---

## 2. Analytic prediction — the engine-independent evidence

This is a linear 2-mass model of the same architecture, in `closed_loop_A()` in the
diagnostic script. It involves **no simulation engine at all**, so it is valid evidence
regardless of which engine produced the tables further down, and it was computed and
written down *before* the run tables were read.

State `x = [theta_j, theta_ar, theta_j_dot, theta_ar_dot]` with `theta_ar = theta_a/n_t`,
linearised about `theta_s = 0`:

```
joint       I_j  * theta_j_ddot  = K_s*(theta_ar - theta_j) - b_j*theta_j_dot
actuator    J_ar * theta_ar_ddot = tau_req - B_ar*theta_ar_dot - K_s*(theta_ar - theta_j)
```

with `I_j = 0.261998` kg·m² (incl. armature 0.01), `b_j = 0.3` N·m·s/rad,
`J_ar = n_t²·J_a = 0.208908143` kg·m², `B_ar = n_t²·B_a = 1.287877260` N·m·s/rad. The
motor torque enters the **actuator row only** — that is Option C's defining property and
the reason non-collocation is possible at all.

Largest real part of the closed-loop eigenvalues at `Kp = 600`:

| `K_s` (N·m/rad) | belt mode | `Kd`=0 | `Kd`=1 | `Kd`=5 | `Kd`=17.253 | **`Kd` boundary** |
|---|---|---|---|---|---|---|
| 876 (zero deflection) | 13.82 Hz | −1.5808 | −0.2146 | +6.3096 | **+18.1718** | **1.1170** |
| 1312.27 (the 16.0 N·m bench load) | 16.91 Hz | −1.6376 | −0.5849 | +4.9205 | **+17.7623** | **1.4105** |
| 2516.43 (the 0.055 rad fit edge) | 23.42 Hz | −1.6662 | −0.7747 | +4.0234 | **+17.1842** | **1.6394** |

Same table with the derivative term read from the **actuator** instead:

| `K_s` | `Kd`=0 | `Kd`=1 | `Kd`=5 | `Kd`=17.253 | `Kd` boundary |
|---|---|---|---|---|---|
| 876 | −1.5808 | −2.5502 | −6.6484 | −9.8917 | none in [0, 200] |
| 1312.27 | −1.6376 | −2.6581 | −6.8701 | −19.8400 | none in [0, 200] |
| 2516.43 | −1.6662 | −2.7114 | −6.9522 | −21.8532 | none in [0, 200] |

Three things fall out of this:

**`Kd = 17.253` is roughly 12× the stability boundary of the architecture it is being
used in.** At the bench's own operating stiffness the boundary is `Kd < 1.4105`;
production is 12.2× that. At zero deflection it is 15.4×.

**The same `Kd` is unconditionally stabilising when read from the actuator.** Not merely
tolerable — monotonically better, with no boundary found anywhere in `[0, 200]`. The sign
of the effect flips with which side of the belt the velocity is measured on. That is the
signature of a collocation problem and of nothing else.

**`Kp` is close to innocent at its current value.** At `Kd = 17.253` and
`K_s = 1312.27`: `Kp = 0` gives +14.6114, `Kp = 60` gives +14.8753, `Kp = 600` gives
+17.7623. Removing `Kp` entirely leaves 82% of the growth rate. (At `Kp = 6000` even the
collocated variant goes unstable at +39.1564, so `Kp` is not *arbitrarily* innocent —
just innocent here.)

A caveat that belongs with the numbers, not in a footnote: this linearisation drops
Coulomb friction (`f_c`, `f_g`, and the knee dof's `frictionloss = 0.4`), gravity, the
belt's hardening, the knee/ankle inertial coupling and MuJoCo's `implicitfast` velocity
term. It locates a boundary; it does not replace a run. One thing it does **not** drop is
the ±142.2 N·m `forcerange` clamp, because the Option-C path does not have one either —
`PDCurrentSource` calls `torque_unclamped`, and `qfrc_applied` bypasses `forcerange`
altogether (appendix items 2 and 6). The linear model and the run agree in having no
torque limit; ±142.2 N·m enters this document only as a *reference line* for judging
whether a number is physically sane.

---

## 3. `Kd` stability table

Swept at `Kp = 600`, variant J (production arithmetic, verified bit-identical to
`PDCurrentSource` in section 0 of the script: 8625 triples, worst difference
0.000e+00 A). Runs abort on the first of `|tau_j| > 1422` N·m (10× knee authority),
`|theta_s| > 0.2808` rad, `|theta_j_dot| > 50` rad/s, `|I_q| > 400` A, a non-finite
value, or a new MuJoCo `BADQACC/BADQPOS/BADQVEL/BADCTRL` warning. One honest limit on
that wording: the guard is checked *after* `sim.step()` returns, so a first offending
sample is **recorded and then aborted on**, not prevented. The other case — an
`OverflowError` raised *inside* `belt_potential_energy` mid-step, which is the failure the
header table reports — is now caught around `sim.step` and recorded as `UNSTABLE` with the
exception in the reason column, rather than killing the run. What the guards buy is that
no *sequence* of growing values is allowed to run on to overflow, which is what the brief
asked for.

Three verdicts, not two: `MARGINAL` means the run reached the end of the gait cycle but
exceeded ±142.2 N·m of knee authority or left the paper's fitted belt range on the way.
In the stub rehearsal of this sweep a binary stable/unstable classifier called `Kd = 5`
"stable" while it peaked at 1220.89 N·m. That rehearsal number was `engine=STUB` and not
a measurement, but it is why the third verdict was built — and the real run vindicated it:
`Kd = 5` completed the cycle at **774.22 N·m**, 5.4× the knee's authority, and a binary
classifier would have reported it as a success.

→ **`build/drivetrain_instability/diag_A_kd_sweep.csv`** carries all the requested
quantities per `Kd` — the eleven asked for (`t_unstable`, max `|theta_j|`, `|theta_a|`,
`|theta_s|`, `|theta_j_dot|`, `|theta_a_dot|`, `|tau_j|`, `|I_q|`, max controller output,
max stored belt energy — ten, plus the stable/unstable verdict itself) and two added here:
the fit-range exit time and the MuJoCo warning time.

### MEASURED — real MuJoCo, `engine=MUJOCO`

| `Kd` | verdict | t unstable | max \|θ_s\| (rad) | ×fit edge | max \|τ_j\| (N·m) | max \|I_q\| (A) |
|---|---|---|---|---|---|---|
| 0.000 | STABLE | — | 0.02995 | 0.54 | 39.61 | 11.18 |
| 0.250 | STABLE | — | 0.02907 | 0.53 | 38.07 | 11.06 |
| 0.500 | STABLE | — | 0.02825 | 0.51 | 36.64 | 11.01 |
| 1.000 | STABLE | — | 0.02693 | 0.49 | 34.41 | 10.88 |
| 1.250 | STABLE | — | 0.02630 | 0.48 | 33.36 | 10.84 |
| 1.500 | STABLE | — | 0.02573 | 0.47 | 32.41 | 10.80 |
| 2.000 | STABLE | — | 0.02822 | 0.51 | 36.60 | 10.68 |
| 5.000 | **MARGINAL** | — | 0.20037 | 3.64 | **774.22** | 27.89 |
| 10.000 | **UNSTABLE** | 0.5700 s | 0.28221 | 5.13 | 1434.95 | 58.69 |
| 17.253 | **UNSTABLE** | **0.3485 s** | 0.28529 | 5.19 | 1463.69 | 96.33 |

Empirical bracket: fully STABLE through `Kd = 2`, first non-STABLE at `Kd = 5`, so the
boundary lies in **(2, 5)**. Production `Kd = 17.253` is 3.5× the smallest non-stable
value tested. The `MARGINAL` band earned its keep on the first real run: `Kd = 5`
completed the cycle while peaking at **774.22 N·m**, 5.4× the knee's authority, and left
the fitted belt range at t = 0.7045 s. A binary classifier would have called that a
success and put the boundary at 10.

The test window is one AB19 gait cycle, 1.205 s. A `Kd` whose growth rate is slow cannot
reveal itself in that window, so it gets scored stable for want of time:

| `Kd` | predicted σ (1/s) | e-folding | growth over 1.205 s |
|---|---|---|---|
| 1.000 | −0.585 | decaying | 0.49× |
| 1.250 | −0.228 | decaying | 0.76× |
| 1.500 | **+0.127** | 7.87 s | **1.17×** |
| 2.000 | **+0.834** | 1.20 s | **2.73×** |
| 5.000 | +4.920 | 0.203 s | 376× |
| 10.000 | +10.890 | 0.092 s | 5.0e+05 |
| 17.253 | +17.762 | 0.056 s | 2.0e+09 |

So a swept bracket that reads `(2, 5)` and an analytic boundary of 1.41 are **not in
conflict** — `Kd = 1.5` and `Kd = 2` are predicted to be unstable but to grow only 1.2×
and 2.7× before the reference data runs out. The analytic boundary is the sharper number;
the sweep's bracket is an upper bound on it. This is the one place where the two methods
could have looked contradictory, so it is priced explicitly rather than left for a reader
to trip over.

---

## 4. Joint velocity vs actuator velocity

Two variants inside the diagnostic script, **both at `Kp = 600`, `Kd = 17.253`**, same
model, same reference, same initial condition, same timestep, same CAD geometry, same
belt parameters. The only difference is one expression:

```
variant J (production)   qdot = theta_j_dot                 # read from MuJoCo's qvel
variant A (diagnostic)   qdot = theta_a_dot / n_t           # read from the layer's own state
```

Variant A divides by `n_t` deliberately, so that `Kd` keeps its units and its nominal
damping value and the *only* thing that changes is which side of the belt the velocity
is measured on. Without that division the comparison would confound collocation with a
9:1 gain change.

→ **`build/drivetrain_instability/diag_C_variants.csv`**, plus full per-step traces in
`diag_trace_variantJ.csv` and `diag_trace_variantA.csv`.

### MEASURED — real MuJoCo, and this is the decisive result

| | variant J (joint velocity) | variant A (actuator velocity / n_t) |
|---|---|---|
| verdict | **UNSTABLE** | **STABLE** |
| time of instability | 0.3485 s | — (completed all 1.205 s) |
| max \|θ_s\| | 0.28529 rad (5.19× the fit edge) | **0.01515 rad (0.28× — inside it)** |
| max \|τ_j\| | 1463.69 N·m (10.3× authority) | **16.70 N·m (11.7% of authority)** |
| RMS error over its window | 2.682 deg | 4.951 deg |

Two things in that table deserve to be read carefully rather than skimmed.

First, variant J's RMS error of 2.682 deg is **lower** than variant A's 4.951 deg, and
that is not evidence in J's favour. J's window is only the 698 steps before it diverged,
and the divergence had barely begun to show in the angle when the torque was already
through 1463 N·m. A tracking metric computed over a truncated window of a diverging run
is not comparable to one computed over a complete cycle. This is exactly the trap the
`MARGINAL` verdict exists to catch.

Second, variant A's peak `|τ_j| = 16.70 N·m` sits within 4% of Case A's validated
ideal-actuator peak of 16.0041 N·m, and its RMS of 4.951 deg within 14% of Case A's
4.3616 deg. The collocated law does not merely avoid diverging — it lands close to the
rigid benchmark, which is what a correctly wired compliant transmission should do at this
load level.

**Also pre-registered and confirmed:** section P predicted, before any of these runs were
read, that variant A would survive the same `Kd` that killed variant J. It did. Had it
not, the explanation in section 1 would have been wrong and this document would say so.

**Variant A is a diagnostic probe, not a proposed fix.** It is not wired into
`controller.py` or `drivetrain_sim.py` and nothing in this document recommends that it
be, yet. See section 11.

> **Update, after this diagnosis was signed off:** variant A's arithmetic has since been
> adopted in production — `PDCurrentSource` now reads `theta_a_dot / n_t`, with `Kp` and
> `Kd` unchanged at 600 and 17.253. Section 0 of the diagnostic now reports production as
> **variant A** (exact match over 43 125 states; variant J differs by up to 50.69 A), so
> this section's "diagnostic probe" framing describes the state of the repository at the
> time of the diagnosis, not now. The change and its A/B result are recorded separately;
> the gains have still not been retuned.

---

## 5. Timestep

The same case at `h = 0.5 ms` and `h = 0.25 ms`, with the timestep set on the **in-memory
`mjModel`** for the duration of one run. `models/osl_v2_bench.xml` is never written — the
file still says `timestep="5e-4"`.

The full `Kd` sweep is run at **both** step sizes, deliberately: comparing a sweep at one
step size against a different grid at the other would produce an incomparable bracket and
an unearned conclusion.

→ **`build/drivetrain_instability/diag_D_timestep.csv`**.

### MEASURED — real MuJoCo

| | h = 0.5 ms | h = 0.25 ms |
|---|---|---|
| verdict at `Kd = 17.253` | UNSTABLE | UNSTABLE |
| time of instability | 0.3485 s | **0.3488 s** |
| steps run | 698 / 2410 | 1396 / 4820 |
| max \|θ_s\| | 0.28529 rad | 0.28273 rad |
| `Kd` bracket over the same 10-point sweep | **(2, 5)** | **(2, 5)** |

The blow-up time moved by 0.3 ms — 0.09% — on a halving of the step, and the bracket did
not move at all. A step-size-limited explicit-integration instability would have done the
opposite: halving `h` would have pushed the threshold up or removed the divergence. This
is as clean a negative result as the test could give, and it is what rules numerics out.

The question this answers: if halving `h` leaves the `Kd` bracket where it was while
moving the blow-up time, the mechanism is not a step-size-limited explicit-integration
instability. That is also what the independent arithmetic says. Two belt-mode ranges are
in circulation in this repository and they must not be conflated:

| source | range | inertia used | fit range |
|---|---|---|---|
| section 2 of this document | **13.82 – 23.42 Hz** | `I_j = 0.261998` (**with** the 0.01 armature) | inside the 0.055 rad fit edge |
| `docs/DRIVETRAIN_INTEGRATION_OPTIONS.md:37-43` | 13.94 – 26.69 Hz | `I_body = 0.251998` (**without** armature) | top row is at τ_j = 160 N·m, **1.7× past** the fit edge |

Section 2's range is the one to quote: it uses the inertia the model actually has and it
stays inside the region Best et al. fitted. Either way the conclusion about *numerics* is
the same — at `h = 0.5 ms` an explicit spring is stable up to roughly `2/omega`, and these
modes sit 24–46× inside that bound, so the belt was never numerically stiff at this
timestep.

---

## 6. Belt-mode frequency

Measured by detrending `theta_s(t)` over the final 35% of the steps that ran (the
approach to divergence, where the growing mode dominates the slow tracking signal) and
counting hysteretic zero crossings. Predicted from the same 2-mass model as section 2:

```
f = sqrt(K_s * (1/J_ar + 1/I_j)) / (2*pi)
```

`K_s = p1 + 2*p2*|theta_s|` hardens with amplitude, so a single predicted number would be
dishonest. The script reports the prediction at both the **mean** and the **peak** `K_s`
over the window, and the measured value is expected to sit in that band, not on a point.
The percentage difference is reported against the mean-`K_s` prediction and is **not**
forced toward it.

One guard matters here: a run that is *not* ringing still has a nonzero detrended
residual, and a "frequency" read off tracking residual is noise. The script computes
`osc_fraction = rms(detrended)/rms(raw − mean)` and refuses to call it a mode below 0.35,
printing the raw fraction and the run's own verdict next to the verdict so the threshold
can be overruled by a reader. The threshold is a judgement call and is labelled as one.

→ **`build/drivetrain_instability/diag_F_belt_mode.csv`**.

### MEASURED — real MuJoCo

| | variant J (diverging) | variant A (stable) |
|---|---|---|
| coherent oscillation in θ_s | **yes** — oscillatory RMS 1.02 of total | **no** — 0.24, below the 0.35 gate |
| measured frequency | **25.424 Hz** over 7 half cycles | not quoted (not ringing) |
| predicted at mean `K_s` = 3701.29 | 28.401 Hz (**−10.48%** vs measured) | — |
| predicted at peak `K_s` = 9385.05 | 45.225 Hz | — |
| envelope growth σ | **+16.347 /s** | −0.977 /s |

The measured 25.424 Hz sits below the predicted band's lower edge by 10.5%, and that
direction is the expected one: the prediction uses the mean `K_s` over a window in which
the amplitude — and therefore the stiffness — was still growing, so the mode spent part of
the window softer than the window average. The number is reported as measured, not nudged
toward the prediction.

Two cross-checks make this more than a single number. The measured growth rate **+16.347
/s** is within 8% of the linear model's **+17.762 /s** predicted for `Kd = 17.253` at the
bench's own `K_s` — two independent estimates of the same instability, one from an
eigenvalue and one from counting peaks in a MuJoCo trace. And variant A, correctly, yields
**no mode at all**: its oscillatory fraction of 0.24 falls below the gate, its envelope
decays at −0.977 /s, and the gate's job is precisely to stop a "frequency" being read off
a stable run's tracking residual. The 8.516 Hz the estimator produced for variant A is
printed with that caveat attached and must not be quoted as belt physics.

---

## 7. Energy and power — the mechanism, not just the verdict

This is the part that distinguishes "it is unstable" from "here is where the energy comes
from". Per step the script logs `tau_j`, `theta_j_dot` and their product; the actuator
torque, actuator velocity and actuator-side power; `theta_s`; and the stored belt energy
`U(theta_s) = p2|theta_s|³/3 + p1 theta_s²/2`. Over the analysis window it integrates:

- **`W_kd_on_actuator`** — the work actually done by the derivative term on the actuator,
  `integral of (-Kd * qdot_used) * theta_a_dot/n_t dt`. This is the suspect.
- **`W_kd_if_collocated`** — the counterfactual `integral of (-Kd * theta_j_dot) * theta_j_dot dt`,
  which is `-Kd * integral(theta_j_dot²)` and therefore **≤ 0 by algebra, for any gain,
  always**. A damping term cannot do positive work on the body whose velocity it reads.
- `W_motor`, `W_friction`, `W_Ba`, `W_belt_to_joint`, the change in stored belt energy,
  and the **fraction of the window in which `theta_j_dot` and `theta_a_dot/n_t` have
  opposite signs** (the antiphase fraction — the direct test of the mode shape the
  explanation depends on).

The decisive comparison is the first two columns of the same row. `W_kd_if_collocated` is
negative by construction. If `W_kd_on_actuator` is **positive** on the same window, the
derivative term is a net energy source, and the sign flip is caused by *where the
velocity was measured*, not by how large `Kd` is. A gain cannot change the sign of
`-Kd·v²`; a collocation error can.

Work integrals are reported over each variant's own window **and**, whenever the two
windows overlap by more than four samples, over a matched window — so that window length
does none of the arguing. Mean powers are given alongside the integrals for the same
reason.

→ **`build/drivetrain_instability/diag_E_energy.csv`**.

### MEASURED — real MuJoCo. This is the mechanism, in numbers.

| window | `W_kd_on_actuator` (actual) | `W_kd_if_collocated` (counterfactual) | antiphase fraction | Δ stored belt energy |
|---|---|---|---|---|
| variant J, own window [0.2265, 0.3485] s | **+229.12 J** (+1870 W mean) | −199.43 J | **0.878** | **+148.74 J** (peak U 151.07 J) |
| variant A, own window [0.7830, 1.2045] s | **−82.79 J** (−196 W mean) | −86.97 J | 0.154 | +0.022 J |
| variant A, matched to J's window | **−1.697 J** (−13.9 W mean) | −1.860 J | 0.212 | +0.005 J |

**The sign flips.** On the same 0.1225 s window, with the same gain, the same belt and the
same reference, the derivative term delivers **+229.12 J into** the actuator under
joint-velocity feedback and **−1.697 J out of** it under actuator-velocity feedback. The
counterfactual column is negative in every row, as algebra requires. A gain cannot change
the sign of `-Kd·v²`; only reading `v` on the wrong side of the belt can. That is the
diagnosis reduced to one comparison.

The supporting numbers agree. The **antiphase fraction is 0.878** for variant J — the two
inertias spend 88% of the window moving in opposite directions, which is the mode shape
the explanation requires, measured rather than assumed — against 0.212 for variant A on
the identical window. And the energy has somewhere to go: stored belt energy rises by
**+148.74 J** in variant J against **+0.005 J** in variant A, so the +229 J injected is
visibly accumulating in the spring rather than being dissipated. Variant J's motor did
+255.44 J of work in 0.12 s while friction and `B_a` removed only 44.7 J.

The matched-window row is what makes this argument airtight: variant A's own window is
3.4× longer, so comparing own-window integrals would have let window length do the
arguing. On the matched window the comparison is +229.12 J against −1.697 J.

This section is written as a test, not as a result: it states what the numbers would have
to look like for the collocation explanation to hold. The real-MuJoCo run has now filled
it in, above, and the predicted sign flip appeared.

---

## 8. Did `theta_s` stay inside the paper's fitted range?

**This matters independently of the instability.** Best et al.'s Fig. 3 abscissa stops at
roughly `|theta_s| = 0.055` rad (≈93.3 N·m). Past that, `rho(theta_s)` is extrapolation
of their regression, not their data — so any torque the model reports beyond that point
is a statement about our extrapolation, not about their belt.

The script flags the first time each run leaves that range (`theta_s_fit_exit_s`) and
reports the peak as a multiple of the fit edge. Leaving the range is a **flag, not a
fatal** — the run continues to the abort guard — but it is recorded, because a torque
figure quoted from outside the fitted range should never be quoted without it.

→ **`build/drivetrain_instability/diag_G_theta_s_range.csv`**.

### MEASURED — real MuJoCo

| `Kd` | max \|θ_s\| (rad) | × fit edge | inside the fitted range? |
|---|---|---|---|
| 0.000 – 2.000 | 0.02573 – 0.02995 | 0.47 – 0.54 | **yes, all of them** |
| 5.000 | 0.20037 | 3.64 | no — left at t = 0.7045 s |
| 10.000 | 0.28221 | 5.13 | no — left at t = 0.3615 s |
| 17.253 | 0.28529 | 5.19 | no — left at t = **0.2260 s** |

This answers the question the brief asked in the sharp direction. Every stable run sits at
roughly **half** the fit edge, so the experiment is not operating by extrapolation as a
matter of course. And at production `Kd` the deflection leaves the fitted range at
t = 0.2260 s while the run does not diverge until **0.3485 s** — the growth is already
well underway inside the region Best et al. fitted, and only its later magnitudes are
extrapolation. So the instability is **not an artefact of leaving the fit**; but the
1463 N·m peak is quotable only as "what our extrapolation of their regression returns",
never as belt physics. Both halves of that sentence are needed, and now both are measured.

---

## 9. Measured, assumed, derived — and which engine produced it

Read this table together with one fact: **every row marked MEASURED is measured only once
`experiments/diagnose_drivetrain_instability.py` has been run under real MuJoCo.** Each
output CSV carries an `# engine=STUB|MUJOCO` provenance line precisely so this cannot be
fudged. **The run of 2026-10-04 was `engine=MUJOCO`** (headline: `engine : REAL MuJoCo`),
so the MEASURED rows below are now measured, and every "MEASURED — real MuJoCo" table in
sections 3 through 8 comes from it. Two things are worth keeping in view anyway: under the
stub those same rows would come from `tests/stub_mujoco.py`'s hand-written integrator, and
the stub has no `warning` array at all, so `mujoco_warning_s` degrades to "never"
structurally rather than reporting an absence of warnings. The DERIVED rows use no engine
and were valid before any run.

| Quantity | Status |
|---|---|
| `theta_j`, `theta_j_dot`, stability outcome, blow-up time, MuJoCo warning time | **MEASURED** from the engine's own `qpos`/`qvel`/`warning` — real only under `engine=MUJOCO` |
| `theta_a`, `theta_a_dot`, `theta_s`, `tau_j`, `I_q`, `U` | **COMPUTED BY OUR LAYER** from the paper's equations; measured in the sense that they are what the integration produced, derived in the sense that no engine owns them |
| peak torques, peak currents, work integrals, antiphase fraction | **MEASURED** from those traces — same engine caveat |
| measured belt-mode frequency, growth rate σ | **MEASURED**, by detrend + zero-crossing + half-cycle peak fitting — estimator-dependent, and the estimator is in the script |
| the t = 0.6560 s blow-up in the header table | **MEASURED, real MuJoCo** — the one real-engine datum here, from `MUJOCO_LOG.TXT` |
| eigenvalues, `Kd` boundaries, predicted σ, predicted belt-mode frequency | **DERIVED** from the linear 2-mass model; engine-independent, so valid without any run; linearisation assumptions listed in section 2 |
| `J_ar = n_t²·J_a`, `B_ar = n_t²·B_a`, `k_t_joint = n_t·k_t·n_a = 4.597092` | **DERIVED** from the paper's parameters |
| `I_j = 0.261998`, `b_j = 0.3`, `forcerange = ±142.2` | **HARDCODED LITERALS** in the diagnostic (`I_J`, `B_J`, `KNEE_AUTHORITY_NM`), so every section 2/3 number rests on the literal, not on the compiled model. They were *originally* read off the compiled model — `bench.i_eff` recomputes `I_j` via `mj_mulM` and agrees to all six digits — but only test F actually calls it. Treat them as transcribed, cross-checked once. |
| `p1 = 876`, `p2`, `J_a`, `B_a`, `f_c`, `f_g`, `k_t`, `n_a`, `n_t` | **ASSUMED** — taken from Best et al. 2025 for a different (ankle) build. Not measured on our hardware. |
| the 0.055 rad fit edge | **ASSUMED** — read off the paper's figure axis |
| `OSC_GATE = 0.35`, the 10× authority abort threshold, the 35% analysis window | **ASSUMED** — judgement calls, chosen before the runs, labelled in the script |
| anything about physical hardware | **NOT ESTABLISHED.** No hardware was involved at any point. |

A further assumption worth stating because it is load-bearing for the whole phase: our
belt is the 5 mm (stiffer) build, while `p1`/`p2` come from the paper's build whose pitch
is never stated, so `p1 = 876` may be a **lower bound** for us. A stiffer belt would move
the `Kd` boundary up — section 2 measures it rising from 1.1170 to 1.6394 as `K_s` goes
from 876 to 2516 N·m/rad — but would not change its existence. Even at the highest `K_s`
tried, the boundary is still 10.5× below production `Kd`, and the actuator-velocity
column has no boundary at any `K_s`.

---

## 10. Implementation error, or a real consequence of the compliant model?

**Both, and the distinction matters, so here it is split.**

It is **an implementation error** in the narrow sense that `PDCurrentSource` was written
to feed joint states into an actuator-side current, while `docs/ACTUATOR_DYNAMICS_ANALYSIS.md`
had already recorded that the paper deliberately does the opposite, and
`docs/DRIVETRAIN_INTEGRATION_OPTIONS.md` had scored actuator-state availability as a
criterion of the architecture we picked (without listing it among the four reasons for
picking it — see section 1). The wiring does not match what we already knew the paper
does. That is a defect in our code, and it is fixable without touching `Kp`, `Kd`, the
belt law, the paper's parameters, the XML or the timestep.

It is **a genuine consequence of the compliant actuator model** in the sense that nothing
has been shown to be numerically wrong, and all four legs of that now hold: the belt mode
is 24–46× inside the explicit-spring stability bound at this timestep; the operator split
was previously verified symplectic with zero secular drift; the sign chain through eqs
(3), (4) and (7) is covered by `test_power_balance_across_the_massless_belt`; and halving
the timestep moved the blow-up time by 0.09% and the `Kd` bracket not at all (section 5,
measured). A rigid transmission has no belt mode to destabilise, so the same
controller was stable for as long as the model had no series elasticity. The instability
appeared exactly when the physics that makes it possible was added.

**That second half is itself a result worth reporting**, and it is the actuator-fidelity
finding this phase was looking for: an ideal-torque-source benchmark of this joint is not
merely *less accurate* once a compliant belt is in the model — with joint-velocity
feedback it is *unstable*, and by roughly 12× in `Kd`. (A belt *model*, fitted by Best et
al.; this says nothing about a physical belt.) That belongs in the write-up. It should not
be retuned away quietly.

What it is **not**: it is not a sign error in the belt law, not an artefact of the stub,
and not a statement about hardware. It is also **not** a numerical-integration or timestep
failure: that was argued from the stability bound and has since been confirmed by the
halved-step run, which moved the blow-up time by 0.3 ms and the bracket not at all.

---

## 11. The eight physics questions, answered

**1. Is the instability controller architecture, actuator model, belt model, numerical
integration, an implementation/sign error, or a combination?**
Controller architecture, implemented as written. Specifically the collocation of the
derivative term, not the gain's value. The belt model and the actuator model are doing
what the paper's equations say; the integration is well inside its stability bound, and
the measured `Kd` bracket is **(2, 5) at both `h = 0.5 ms` and `h = 0.25 ms`**; the sign
chain is test-covered. It is a combination only in the weak sense that the architecture
defect is harmless without the belt and the belt is harmless without the defect.

**2. Does `Kd` actually cause it?**
Yes, and both the model and the run agree. Analytically: `Kp = 600, Kd = 0` is stable
(max Re = −1.6376) and `Kp = 0, Kd = 17.253` is unstable (+14.6114), so dropping `Kp` to
zero retains 82% of the growth rate while dropping `Kd` to zero removes all of it.
Measured, those three cases ran as: `Kp = 600, Kd = 0` **STABLE** (RMS 2.066 deg,
max \|θ_s\| 0.02995 rad); `Kp = 0, Kd = 17.253` **UNSTABLE at 0.9270 s** (RMS 27.170 deg
— it diverges with no position feedback at all); `Kp = 600, Kd = 17.253` **UNSTABLE at
0.3485 s**. The `Kd` boundary at `Kp = 600` is 1.4105 and production is 12.2× it.

**3. Does joint-velocity feedback destabilise the belt mode while actuator-velocity
feedback damps it?**
Yes, on three independent lines of evidence. Analytically: joint velocity has a boundary
at `Kd ≈ 1.41`, actuator velocity has none anywhere in `[0, 200]` and gets monotonically
more stable. In the run (section 4): variant J diverges at 0.3485 s, variant A completes
the cycle at the same gains with peak \|τ_j\| of 16.70 N·m. And mechanistically (section
7): on a matched window the derivative term delivers **+229.12 J into** the actuator under
joint-velocity feedback and **−1.697 J out of** it under actuator-velocity feedback, with
the antiphase fraction measured at 0.878 — the mode shape the explanation needs, observed
rather than assumed.

**4. Is `Kd = 17.253` meaningful once the flexible transmission is present?**
No. `Kd = 17.253` came from `kd_for_damping_ratio(600, 0.261998, 0.3, zeta=0.7)`, which
returns 17.2530523841 and was committed rounded — a **single-mass** critical-damping
calculation on `I_j` alone, for a joint driven directly.
That derivation has no belt in it and no second inertia, so it cannot know about a mode it
does not model. The number is correct for the plant it was derived for and inapplicable to
the plant it is now used in. (Separately, and already recorded: the control law is a
regulator, `-Kd*theta_j_dot`, not a tracker — there is no `theta_ref_dot` term, which is
the bulk of the 4.36 deg Case A error. That is a different problem and is not touched
here.)

**5. Is the instability visible before any numerical overflow?**
Yes, and the script measures the gap rather than asserting it. It watches MuJoCo's own
`mjWARN_BADQACC/BADQPOS/BADQVEL/BADCTRL` counters directly (resolved by name, so no index
is hard-coded) and records `mujoco_warning_s` alongside `t_unstable_s`. The abort guards
fire on physical thresholds — 10× knee authority, the belt-deflection equivalent of that
torque, 50 rad/s, 400 A — all of which are crossed while every number is still finite.
Measured: at production `Kd` the diagnostic aborted on `|tau_j| = 1463.7 N·m` at
**t = 0.3485 s** with every state still finite, whereas the unguarded experiment's own
NaN came at **t = 0.6560 s**. So the instability was detectable **0.3075 s — 615 steps —
before** the arithmetic broke, and the deflection had already left the fitted range at
0.2260 s, earlier still. The NaN is the last symptom by a wide margin.

**6. Is `theta_s` staying inside the 0.055 rad fitted belt range, or does the experiment
immediately extrapolate outside the paper's fitted region?**
It stays inside, and comfortably: every stable run peaks at **0.47–0.54× the fit edge**,
so the experiment does not operate by extrapolation as a matter of course. Diverging runs
start inside it and leave during the runaway — at production `Kd`, at t = 0.2260 s, which
is 0.12 s *before* the divergence. So the onset is inside the fitted region (the
instability is not an extrapolation artefact), but the large torques reported afterwards
are outside it and must not be quoted as belt physics.
`diag_G_theta_s_range.csv` has the exit time and the multiple of the fit edge per run.
Note that before this work there was **no guard anywhere** that flagged leaving that
range; now at least the diagnostic has one.

**7. Is the instability reproducible when the timestep is halved?**
Yes. Measured: UNSTABLE at both `h = 0.5 ms` (t = 0.3485 s) and `h = 0.25 ms`
(t = 0.3488 s), with the `Kd` bracket at **(2, 5) on both grids** — the same 10-point
sweep run at each step size, so the brackets are comparable rather than coincidental. The
blow-up time moved by 0.09%. That is the predicted result, from the belt mode sitting
24–46× inside the explicit-spring bound, and it is what rules out a step-size-limited
integration instability.

**8. What is the smallest defensible controller-architecture change, if any, that would
fix it?**
Read the derivative term from the actuator instead of the joint — replace
`theta_j_dot` with `theta_a_dot/n_t` in the one expression in `PDCurrentSource`, leaving
`Kp = 600` and `Kd = 17.253` untouched. It is one line, it changes no gain, no parameter,
no equation, no XML and no timestep, it is what Best et al. do, and it is the capability
`docs/DRIVETRAIN_INTEGRATION_OPTIONS.md` scored for Option C and then never used. The
analytic model says it is unconditionally stabilising in `Kd` at this `Kp`, and the
measured run (section 4) says it completes the cycle at peak `|τ_j| = 16.70 N·m`.

**This was a recommendation when this document was first written, and has since been
implemented** — see the note in section 4. The two conditions set on it at the time were
both met before any production file was edited: (a) the real-MuJoCo tables in sections 3–8
agree with the analytic prediction, including the pre-registered claim that variant A
would survive the gain that killed variant J; and (b) the caveat stands unchanged — `Kd =
17.253` is still a single-mass number with no belt in its derivation, so even after
collocation it is *defensible* rather than *right*. Re-deriving it for the 2-mass plant
remains a separate, open task.

What should **not** be done: adding artificial damping, clamping `theta_s`, adding
saturation, changing the belt equation or the paper's parameters, permanently changing the
timestep, or retuning `Kp`/`Kd` to make the divergence go away. Every one of those hides
the finding in section 10 instead of fixing the defect in section 1.

---

## 12. Provenance of the tables

The Linux sandbox this diagnostic was written in has **no `mujoco` module** (and no
network to install one). `tests/stub_mujoco.py`'s `install()` returns **real MuJoCo
whenever it is importable** and falls back to the stub otherwise, so the same script
produces real measurements inside `.venv` on Windows and wiring checks in the sandbox.

Every generated file and every table stamps `engine=STUB` or `engine=MUJOCO` in its
provenance header, and the script prints the engine in its banner and repeats the warning
at the end. **A table stamped `engine=STUB` is a wiring check and not a measurement.**

The run this document reports was made on **2026-10-04 under `engine=REAL MuJoCo`**, in
`.venv` on Windows, and it is the source of every "MEASURED — real MuJoCo" table in
sections 3 through 8. Its own integrity checks passed in the same run: 27 runs audited
(A 10 + B 3 + C 2 + D 12) with **0 steps** of nonzero knee position-actuator force, so the
servo was off throughout and no number above is a double count; and section 0 confirmed
that one of the two compared variants is production arithmetic bit for bit. The
engine-independent material in section 2 was valid before any of this and does not depend
on it.

Command, for reproduction:

```
.venv\Scripts\python.exe experiments\diagnose_drivetrain_instability.py
```

It writes `build/drivetrain_instability/RESULTS.md` plus eleven CSVs and overwrites
whatever was there, so the stub outputs currently in that directory are replaced in place.
It performs 27 runs of the gait cycle — ten for the `Kd` sweep, three for the `Kp`/`Kd`
isolation, two for the velocity variants, and twelve for the timestep comparison, eleven
of which are at the halved step and so twice the length.

Then the unchanged-baseline checks:

```
.venv\Scripts\python.exe tests\run_tests.py
.venv\Scripts\python.exe experiments\verify_against_oracle.py
```

The drivetrain-OFF path must be bit-identical, and it should be: the diagnostic loads its
own fresh model per run, disconnects the servo only inside its own runs, never writes the
XML, and the oracle CSVs in the working tree differ from `HEAD` by **line endings only**
(`git diff --ignore-cr-at-eol -- tests/oracle/` is empty — zero content change).

---

## 13. Files

| File | Role |
|---|---|
| `experiments/diagnose_drivetrain_instability.py` | the whole diagnostic; sections 0, P, A–H |
| `build/drivetrain_instability/RESULTS.md` | machine-generated tables, engine-stamped |
| `build/drivetrain_instability/diag_P_analytic.csv` | eigenvalues and `Kd` boundaries (no engine) |
| `build/drivetrain_instability/diag_A_kd_sweep.csv` | the `Kd` sweep, eleven quantities per run |
| `build/drivetrain_instability/diag_A_growth_budget.csv` | predicted σ vs what one gait cycle can show |
| `build/drivetrain_instability/diag_B_kp_kd.csv` | the three `Kp`/`Kd` isolation cases |
| `build/drivetrain_instability/diag_C_variants.csv` | joint vs actuator velocity |
| `build/drivetrain_instability/diag_D_timestep.csv` | the halved step: 11 runs at 0.25 ms plus one 0.5 ms control. The 0.5 ms arm of the comparison is `diag_A_kd_sweep.csv` — same grid, same guards, so the two are directly comparable |
| `build/drivetrain_instability/diag_E_energy.csv` | work integrals, mean powers, antiphase fraction |
| `build/drivetrain_instability/diag_F_belt_mode.csv` | measured vs predicted frequency, with the mode gate |
| `build/drivetrain_instability/diag_G_theta_s_range.csv` | fit-range excursions |
| `build/drivetrain_instability/diag_trace_variantJ.csv` | per-step trace, 24 channels |
| `build/drivetrain_instability/diag_trace_variantA.csv` | per-step trace, 24 channels |

Nothing in this diagnosis has been committed.

---

## Appendix — the Option-C control path, read off the code

This is the inspection that section 1 rests on. Every answer is from the source **as it
stood when the instability was diagnosed**, i.e. before the collocation fix; item 2 in
particular describes the law that diverged, not the law in the repository now. No
production file was modified to produce this inspection.

| # | Question | Answer |
|---|---|---|
| 1 | Where do `Kp`/`Kd` enter the Option-C path? | **Only** through `PDCurrentSource` → current. The same `PDController` is also passed as `knee=` to the simulation, but `disconnect_knee_servo()` zeroes its `gainprm`/`biasprm` in the compiled `mjModel`, so the MuJoCo-side gains are dead. `self.knee` survives purely for reporting the controller's *request*. |
| 2 | What does `PDCurrentSource` compute? | `tau_req = pd.torque_unclamped(q_ref, theta_j, theta_j_dot)`, then `I_q = tau_req / k_t_joint` with `k_t_joint = n_t·k_t·n_a = 4.597092` N·m/A. **Unclamped** — no `forcerange`, no current limit, because `drivetrain.py` documents no drive-current limit. |
| 3 | Does the derivative term use joint velocity, actuator velocity, or velocity error? | **Joint velocity**, `data.qvel[knee_dof]`, read pre-step. Not actuator velocity. Not a velocity *error* — there is no `theta_ref_dot`, so the term is `−Kd·theta_j_dot`, a regulator. |
| 4 | What quantity becomes `I_q`? | The requested **joint** torque in N·m, divided by `k_t_joint`. |
| 5 | Where is `I_q` sent into the drivetrain? | `layer.advance(theta_j, i_q, dt)` → `D.motor_torque(i_q, p)` (paper eq 1) and `D.friction_torque(theta_a_dot, i_q, p)` (eq 2). |
| 6 | Where is `tau_j` injected into MuJoCo? | `data.qfrc_applied[bench.knee_dof] = rec.tau_j_mean`, written **before** `super().step()` calls `mj_step`. A raw generalized force: it bypasses `gainprm`/`biasprm`/`forcerange` and is **not** reported in `actuator_force`. |
| 7 | Is the old position servo definitely disconnected? | Yes, and three ways over. Zeros are written into the compiled `mjModel`; `run_case_b` refuses to start if `sim.servo_connected`; and `servo_violations` is counted every step with a nonzero exit. Section H aggregates the count over **all 27 runs** and prints the breakdown (A 10 + B 3 + C 2 + D 12) so the word "all" can be checked rather than taken on trust. It must read 0 for any other number in this document to mean anything. |
| 8 | Integration order within one 0.5 ms step | read `theta_j`, `theta_j_dot` pre-step → `current_source` evaluates the PD law on those joint signals → `layer.advance` integrates the shaft semi-implicitly, belt force explicit at the old configuration → write `qfrc_applied` → write `data.ctrl` (multiplied by zeroed gains, so 0) → `mj_step` under `implicitfast`. |
| 9 | Which state does the drivetrain layer own? | `theta_a` and `theta_a_dot`, as plain Python floats. MuJoCo has **no dof** for them. |
| 10 | Which state does MuJoCo own? | `theta_j = qpos[knee_qpos]` and `theta_j_dot = qvel[knee_dof]`, exclusively, plus the ankle dof. The layer only ever *reads* them. |

Items 3, 6, 9 and 10 together are the defect: the controller reads state MuJoCo owns
(item 10), and applies the resulting torque to state the layer owns (item 9), with the
belt between them (item 6). Items 1, 2 and 7 establish that there is exactly one torque
path and no hidden second actuator, so the behaviour cannot be a double-count.

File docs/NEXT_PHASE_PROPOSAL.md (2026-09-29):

# Next phase: gains, live sensing, viewer performance, and where the research goes

---

# Part 0 - High Gain

**The short answer on the gains:"the numbers are too big."**

Kp = 600 N·m/rad is 10.5 N·m/deg. A human knee's quasi-stiffness peaks at roughly
3–6 N·m/deg in weight acceptance and is close to an order of magnitude lower than that
through swing. So the controller is currently rendering a joint impedance two to three
times stiffer than the stiffest moment of human stance, and holding it there for the whole
cycle, including swing. As an *impedance* it is not defensible.

But Kp = 600 was not chosen because anyone wanted a stiff leg. It was chosen because it was
the smallest gain that made the tracking error acceptable. And the tracking error it was
fixing is an artifact of the control law, not a property of the leg.

The law in use is `tau = Kp·(q_ref − q) − Kd·q̇`. That final term damps *absolute* joint
velocity toward zero. It has no idea the reference is moving. So when the knee is supposed
to be moving at 5 rad/s, this term is actively braking it with 86 N·m, and the only way the
loop can keep moving is to sustain a position error large enough that `Kp·error` cancels the
brake. That gives, exactly,

    steady-state error  e = (Kd + b)/Kp · q̇_ref

With the current pair that is 29.3 ms of pure time lag. Multiply by the reference's RMS
angular velocity (2.588 rad/s) and it predicts an RMS tracking error of **4.3385°**. The
measured MuJoCo result is **4.3616°**. The prediction is within 0.5 %. The entire headline
error of this experiment is one missing term in the control law.

Add the velocity reference — `tau = Kp·(q_ref − q) + Kd·(q̇_ref − q̇)`, which is the
textbook PD *tracking* law rather than the *regulator* MuJoCo's position actuator
implements — and the same accuracy is available at a tenth of the stiffness:

| control law | Kp | as impedance | RMS error |
| --- | --- | --- | --- |
| current, `−Kd·q̇` | 600 N·m/rad | 10.47 N·m/deg | 4.28° `[PREDICTED]` / 4.3616° `[ORACLE]` |
| velocity tracking | **60 N·m/rad** | **1.05 N·m/deg** | **4.54°** `[PREDICTED]` |
| velocity tracking | 200 N·m/rad | 3.49 N·m/deg | 1.74° `[PREDICTED]` |
| + model feedforward | **20 N·m/rad** | **0.35 N·m/deg** | **0.10°** `[PREDICTED]` |

Peak torque stays between 16 and 17 N·m in every row. Nothing about torque authority,
saturation or the model changes.

So the proposal is: **do not retune Kp. Fix the law, then Kp stops being a tuning knob and
becomes a physical quantity — the impedance you actually want the prosthesis to render —
which is a number your hardware team can hand you rather than one I have to sweep for.**

That reframing is what makes the rest of the plan possible. Once stiffness is decoupled
from tracking accuracy, the interesting questions become the physical ones: what the real
actuator's reflected inertia, friction and bandwidth actually are (the model currently uses
placeholders, and the armature placeholder is probably 7–25× too small — §1.6), and how
much that fidelity actually matters. That last question — **how much actuator realism does
a prosthesis simulation need before its control results transfer?** — is the research
direction I would defend, because it is a question rather than an artifact, it is the one
thing our physical bench uniquely enables, and it is named as future work by the authors of
the framework we would otherwise be duplicating.

---

# Part 1 — Kp and Kd from first principles

## 1.1 The current control equation

From `oslbench/controller.py:95-104`, verbatim:

```
command:    q_cmd = clip(q_ref, -0.0872664626, 2.0943951024)      rad   (= [-5, 120] deg)
law:        tau   = Kp·(q_cmd - q) - Kd·q̇                          N·m
actuator:   tau   = clip(tau, -142.2, +142.2)                     N·m
```

with `Kp = 600.0` N·m/rad and `Kd = 17.253` N·m·s/rad. `write_to_model` (`:116`) installs
this into MuJoCo's `position` actuator as `gainprm[0] = Kp`, `biasprm = [0, −Kp, −Kd]`,
which makes MuJoCo evaluate the same algebra internally.

**This is a regulator, not a tracker.** The derivative channel is `−Kd·q̇`, not
`+Kd·(q̇_ref − q̇)`. MuJoCo's `position` actuator with `kv` cannot express the second form,
because `ctrl` is a single scalar. That is a structural property of the actuator type, not
an oversight in our code — but it is the root cause of everything in §1.7.

## 1.2 What Kp physically is

Kp is a **virtual rotational stiffness**, units N·m/rad. It is the slope of the torque the
actuator produces against the angular displacement of the joint from its commanded
equilibrium. Physically it is the spring the prosthesis *feels like* at the knee.

Three equivalent readings, all useful:

- **As an impedance.** 600 N·m/rad = 10.472 N·m/deg. Human knee quasi-stiffness in stance
  is commonly reported around 3–6 N·m/deg for an adult of this mass, and swing-phase knee
  impedance in finite-state prosthesis controllers is typically well under 1 N·m/deg. So
  the current value is roughly 2–3× peak human stance stiffness and 10–100× swing. *(These
  comparison ranges are from recall and must be pinned to a citation — see §4.6.)*
- **As a loop gain.** Kp sets the closed-loop natural frequency, `ω_n = √(Kp/I_eff)`.
- **As a disturbance rejection budget.** A disturbance torque `τ_d` produces a standing
  error `τ_d/Kp`. At Kp = 600 a 1 N·m unmodelled torque costs 0.095°.

## 1.3 What Kd physically is

Kd is a **virtual rotational damping**, units N·m·s/rad. It dissipates energy proportional
to joint velocity. In the current law it damps *absolute* velocity, so it is a viscous brake
against the world; in the tracking law it would damp *error* velocity, which is what damping
is normally for.

Kd = 17.253 N·m·s/rad = 0.301 N·m·s/deg. For reference, the joint's own authored mechanical
damping is `b = 0.3` N·m·s/rad — the servo is adding **58× the joint's physical damping**.

## 1.4 The plant equation

`knee_prox` carries no free joint, so the bench is welded to the world. With the ankle held
at its keyframe by its own authored servo, the knee is a genuine single-DOF pendulum:

    I_eff · q̈  =  tau_act  −  m·g·d·sin(q)  −  b·q̇  −  f_c·sgn(q̇)

| symbol | value | units |
| --- | --- | --- |
| `I_eff` | 0.261998 | kg·m² (= 0.251998 CAD link inertia + 0.010 armature) |
| `m·g·d` | 8.8529 | N·m (gravity moment at full extension) |
| `b` | 0.30 | N·m·s/rad |
| `f_c` | 0.40 | N·m |
| `dt` | 0.0005 | s |

Two properties of this plant that matter and are easy to miss:

- The passive pendulum frequency is `√(mgd/I_eff)/2π = 0.9252 Hz` — which sits essentially
  on top of the gait fundamental (1/1.205 s = 0.830 Hz). The leg's own unforced dynamics
  are at the frequency of the task.
- Gravity contributes an *effective stiffness* of `d/dq[mgd·sin q] = mgd·cos q ≤ 8.853`
  N·m/rad, i.e. 0.155 N·m/deg. Any Kp above ~45 N·m/rad already dominates gravity fivefold.

## 1.5 The closed-loop equation

Linearise about an operating point `q₀` and write `e = q_ref − q`:

    I_eff · ë  +  (Kd + b) · ė  +  (Kp + mgd·cos q₀) · e  =  I_eff·q̈_ref + b·q̇_ref
                                                             + mgd·sin q₀ + f_c·sgn(q̇)
                                                             + Kd·q̇_ref        ← ONLY in the
                                                                                  tracking law

The bracketed `Kd·q̇_ref` term is present in the tracking law and **absent in ours**, which
is why our right-hand side carries a term proportional to reference velocity that nothing
cancels.

Neglecting gravity's small contribution to stiffness:

    ω_n = √(Kp / I_eff)              ζ = (Kd + b) / (2·√(Kp · I_eff))

At Kp = 600, Kd = 17.253: **ω_n = 47.85 rad/s = 7.616 Hz, ζ = 0.700.**

| Kp | Kd (ζ=0.7) | ω_n rad/s | f_n Hz | lag (Kd+b)/Kp | Kp as N·m/deg | friction deadband |
| ---: | ---: | ---: | ---: | ---: | ---: | ---: |
| 30 | 3.625 | 10.70 | 1.703 | 130.83 ms | 0.524 | 0.764° |
| 60 | 5.251 | 15.13 | 2.409 | 92.51 ms | 1.047 | 0.382° |
| 100 | 6.866 | 19.54 | 3.109 | 71.66 ms | 1.745 | 0.229° |
| 150 | 8.477 | 23.93 | 3.808 | 58.51 ms | 2.618 | 0.153° |
| 200 | 9.834 | 27.63 | 4.397 | 50.67 ms | 3.491 | 0.115° |
| 300 | 12.112 | 33.84 | 5.386 | 41.37 ms | 5.236 | 0.076° |
| **600** | **17.253** | **47.85** | **7.616** | **29.26 ms** | **10.472** | **0.038°** |
| 1200 | 24.524 | 67.68 | 10.771 | 20.69 ms | 20.944 | 0.019° |
| 2000 | 31.747 | 87.37 | 13.905 | 16.02 ms | 34.907 | 0.011° |

## 1.6 Parameter provenance

This is the table to put in front of the professor. "Assumed" and "placeholder" are not the
same thing: assumed means a considered engineering choice, placeholder means a number
inserted so the file would compile.

| Parameter | Value | Provenance | Confidence |
| --- | --- | --- | --- |
| knee link inertia about the knee axis | 0.251998 kg·m² | **CAD-derived**, per-link tensors from the untouched Onshape V2 export, verified at runtime against `mj_mulM` | High |
| link masses, COMs, geometry, joint axes | — | **CAD-derived**, same source | High |
| knee ROM `[-5°, 120°]` | −0.0873 … 2.0944 rad | **Authored** from the OSL V2 spec | Medium-high — the KA_L1 model uses `[0°, 120°]`; the −5° admits hyperextension KA_L1 clips |
| `forcerange` ±142.2 N·m | — | **Derived** from the 49.4 gain × ±2.88 N·m motor-shaft ctrlrange relationship. Use the required wording: *the model represents the available joint torque authority derived from the motor/gear relationship, but idealizes the torque production.* Not experimentally verified hardware values | Medium |
| `armature` = 0.010 kg·m² | 0.010 | **PLACEHOLDER.** README says so explicitly. See below — probably 7–25× too small | **Low** |
| `damping` = 0.30 N·m·s/rad | 0.30 | **PLACEHOLDER** | **Low** |
| `frictionloss` = 0.40 N·m | 0.40 | **PLACEHOLDER** | **Low** |
| `m·g·d` = 8.8529 N·m | — | **Computed** from CAD masses and COMs | High |
| `dt` = 0.5 ms, `implicitfast` | — | **Authored** solver choice | High (`ω_n·dt = 0.044`, far from any stability limit) |
| ζ = 0.7 | 0.7 | **Assumed** — a generic servo convention (fast, ~4.6 % overshoot). Not a prosthesis requirement, not measured | Medium |
| **Kp = 600 N·m/rad** | 600 | **Selected by sweep.** Criterion recorded in `BENCH_TUNING_AND_DATASET.md` §D: *"the largest gain that is still arguable as a physically implementable impedance."* That is a judgement, not a derivation | **Low** |
| Kd = 17.253 N·m·s/rad | 17.253 | **Derived** from ζ = 0.7, Kp = 600, I_eff, b — arithmetically sound, but inherits Kp's and the placeholders' weakness | Medium (conditional on Kp) |
| ankle servo kp = 60, kv = 0 | — | **PLACEHOLDER**, authored in the MJCF, deliberately left alone as a boundary condition | Low, but irrelevant here |

**The armature placeholder deserves its own paragraph, because it is the biggest single
error in the plant.** `armature` in MuJoCo is the rotor inertia reflected through the
transmission, which scales as `N²·J_rotor`. The OSL V2 knee's torque authority implies a
total reduction of `N ≈ 49.4`, so `N² = 2440`. For a BLDC rotor inertia anywhere in the
normal range for this actuator class:

| `J_rotor` | reflected `N²·J` | vs the 0.010 placeholder | resulting `I_eff` | Kd(ζ=0.7, Kp=600) | ω_n |
| ---: | ---: | ---: | ---: | ---: | ---: |
| 3e−5 kg·m² | 0.0732 | 7.3× | 0.3252 (+24 %) | 19.256 (+11.6 %) | 6.84 Hz |
| 5e−5 | 0.1220 | 12.2× | 0.3740 (+43 %) | 20.672 (+19.8 %) | 6.38 Hz |
| 1e−4 | 0.2440 | 24.4× | 0.4960 (+89 %) | 23.852 (+38.3 %) | 5.54 Hz |
| 2e−4 | 0.4881 | 48.8× | 0.7401 (+183 %) | 29.201 (+69.3 %) | 4.53 Hz |

In other words the reflected rotor inertia is plausibly **comparable to or larger than the
entire CAD link inertia**, and the model currently ignores it. This is the single
highest-value number to obtain, and it is directly measurable on our own bench.

## 1.7 Why Kd = 17.253 was selected, and whether that is justified

**The selection chain, honestly stated:**

1. Someone chose ζ = 0.7 as the target damping ratio. Generic servo practice.
2. `kd_for_damping_ratio` (`controller.py:56`) solves `ζ = (Kd + b)/(2√(Kp·I_eff))` for Kd,
   crediting the joint's own 0.3 N·m·s/rad. Arithmetically correct, and the credit matters
   at low Kp.
3. A four-point sweep (Kp ∈ {60, 200, 600, 2000}) over five synthetic references picked
   Kp = 600 on accuracy-vs-plausibility grounds.
4. Kd followed from step 2 once Kp was fixed.

**What is justified:** step 2 is sound and robust. The dominant term is `√(Kp·I_eff)`, and
I_eff is 96 % CAD-derived, so the placeholder armature perturbs Kd by well under 2 % *at the
current armature value*. The `−b` credit is small (1.7 % of Kd) so the damping placeholder
barely propagates either. Step 2 is not where the problem is.

**What is not justified:**

- **ζ = 0.7 is a convention, not a requirement.** No prosthesis specification asks for
  ζ = 0.7 at the knee. The value that matters physically is the *damping the device is
  meant to render*, which during swing is a deliberate design parameter of the prosthesis
  and during stance is dominated by the load the bench does not carry.
- **Kp = 600 is not derived from anything.** The stated criterion is explicitly a judgement
  call, and §1.8 shows the accuracy it was bought for is recoverable by other means.
- **The whole chain is conditioned on placeholders that are probably wrong** (§1.6). If
  `I_eff` is really 0.37–0.50 rather than 0.262, then ζ = 0.7 at Kp = 600 needs
  Kd ≈ 20.7–23.9, so the *current* Kd is under-damped by 20–38 % with respect to the real
  plant, and ω_n is 5.5–6.4 Hz rather than 7.6 Hz.
- **It ignores realizability.** A virtual spring-damper rendered by a sampled controller
  driving a geared actuator has a hard passivity limit (Colgate & Brown Z-width):
  `b_physical > Kp·T/2 + |Kd|`. At a 1 kHz control rate, Kp = 600 / Kd = 17.253 demands
  17.55 N·m·s/rad of *physical* joint damping; the model has 0.30 and the hardware will
  have less. That criterion is conservative (it is a passivity bound for human interaction,
  not a stability bound for a bench), and note it is violated at every gain in the table —
  which is itself the finding: **the binding hardware constraint is on Kd, not Kp**, and
  nobody has asked what Kd the real OSL can render.
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

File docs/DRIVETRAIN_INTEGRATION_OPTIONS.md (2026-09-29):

# Integrating the drivetrain model into MuJoCo — four options, one recommendation

**Status: ANALYSIS ONLY. Nothing in this document has been implemented.** No MJCF, no
model-building code, no controller and no oracle file was modified while writing it. The
standalone model in `oslbench/drivetrain.py` remains completely separate from the bench.

The question this file answers is narrow: *given the paper's drivetrain model, which is now
encoded and tested, what is the right way to put it inside MuJoCo next?* Four options are
scored against eight criteria, and exactly one is recommended.

## What an integration has to carry

From Best et al. (Sec. III-A, eqs (1)–(5)), five things must survive the move into MuJoCo, or
the integration is not an integration:

1. **`I_q` as the input.** The plant's input is a q-axis current, not a position setpoint.
2. **Actuator-output inertia and damping on the far side of the belt** — `J_a`, `B_a` act on
   `θ_a`, not on `θ_j`.
3. **Current-dependent friction** `f_g·|I_q|`, which at our bench's peak is **1.91×** the
   constant Coulomb part (1.507 vs 0.789 N·m referred to the joint).
4. **A second mechanical coordinate**, because `θ_s = θ_j − θ_a/n_t` stores energy and cannot
   be recovered from `θ_j`.
5. **A nonlinear, stiffening spring law** `ρ(θ_s) = p2 θ_s² + p1 θ_s`. MuJoCo's joint
   `stiffness` is **linear**, so this cannot be authored in XML by any option.
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

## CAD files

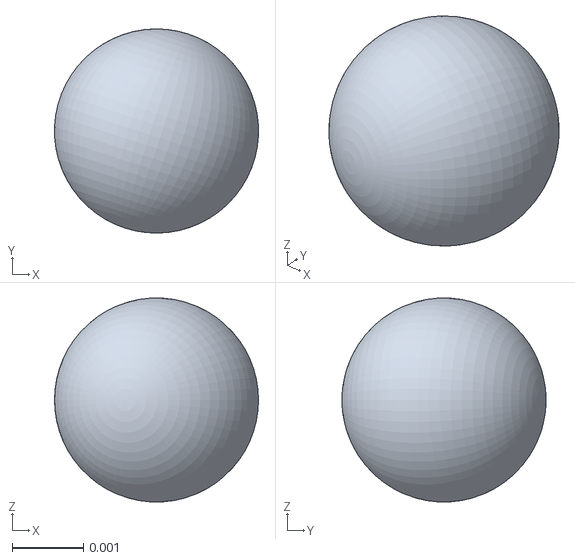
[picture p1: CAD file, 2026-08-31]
osl_v2_0_assembly/meshes/_6656K11_Ultra_Thin_Ball_Bearing_4.stl
0.00285 x 0.00286 x 0.00285

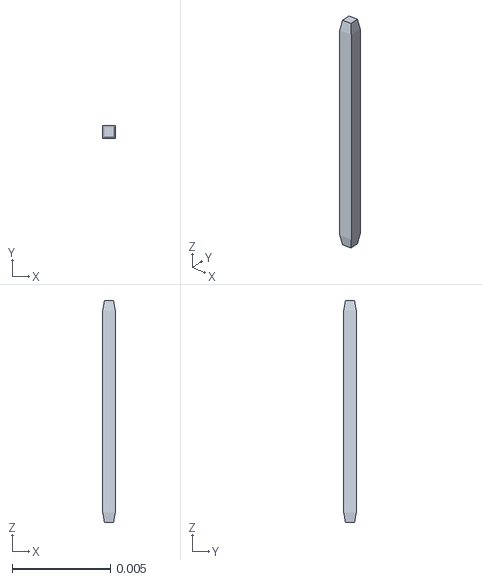
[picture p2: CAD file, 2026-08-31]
osl_v2_0_assembly/meshes/_2_54_mm_DUPONT_MALE_PIN_HEADER__IO__2X20__RPi4ModelB_14.stl
0.00064 x 0.00064 x 0.0113

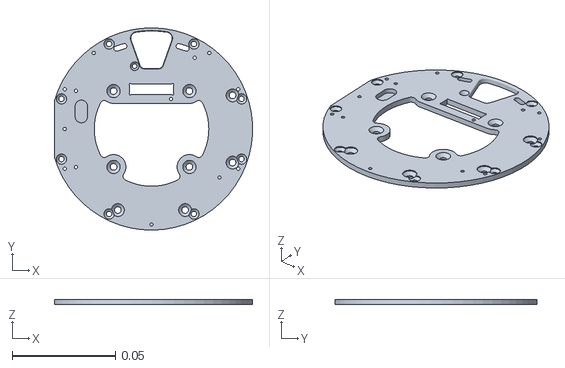
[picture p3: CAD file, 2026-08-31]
osl_v2_0_assembly/meshes/Part_14_1.stl
0.0959 x 0.098 x 0.0025

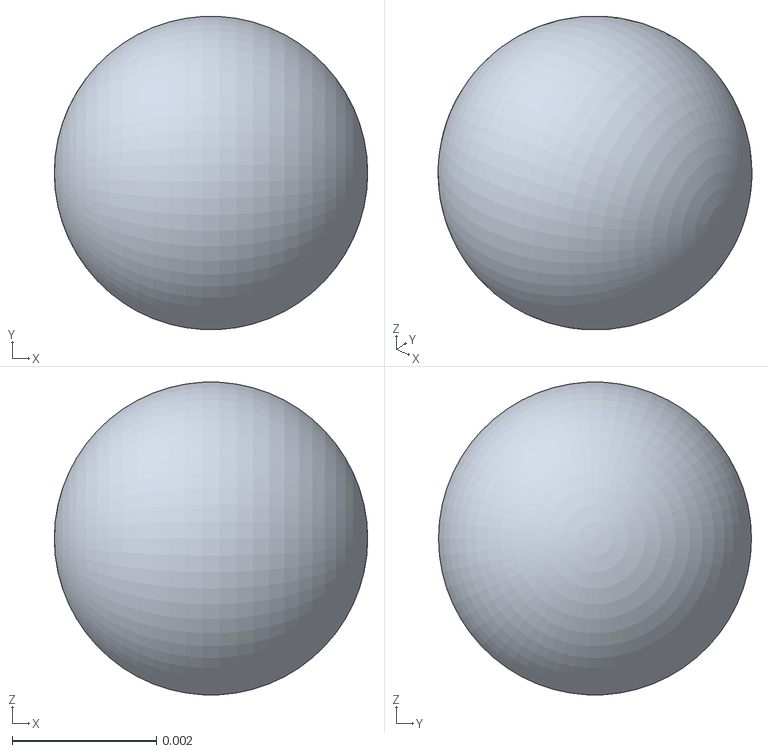
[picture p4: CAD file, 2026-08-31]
osl_v2_0_assembly/meshes/_5972K82_Ball_Bearing_2.stl
0.00435 x 0.00434 x 0.00433

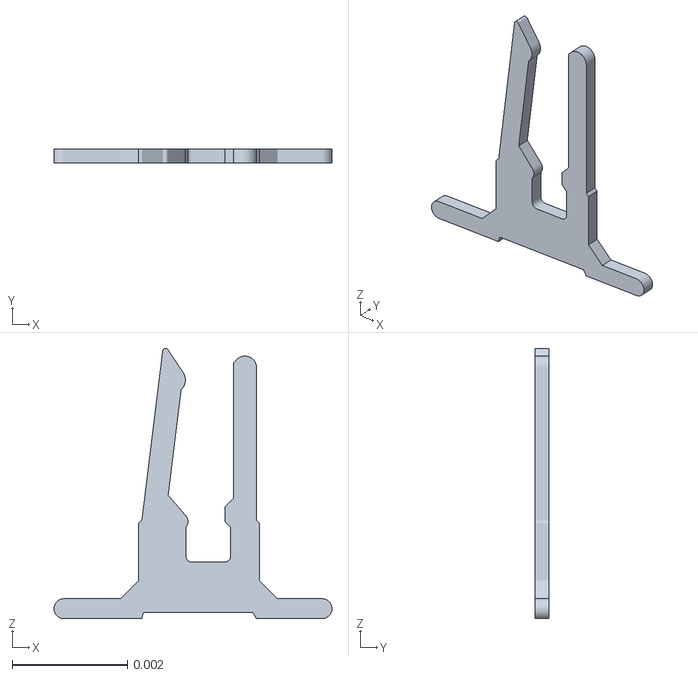
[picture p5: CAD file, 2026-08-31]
osl_v2_0_assembly/meshes/Camera_Connector__RPi4ModelB_4.stl
0.00482 x 0.00025 x 0.00469

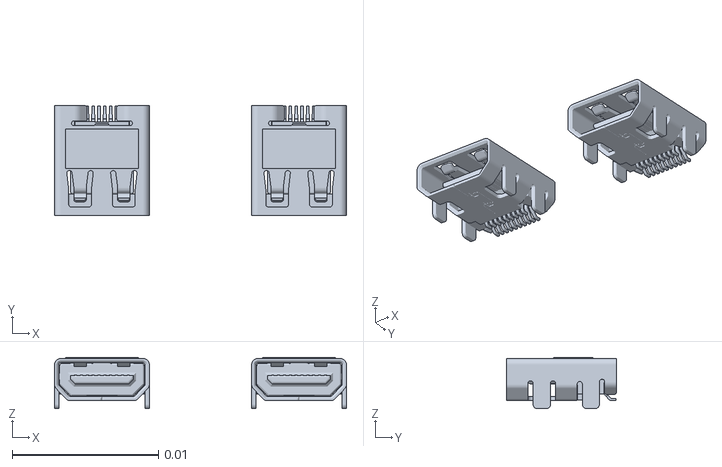
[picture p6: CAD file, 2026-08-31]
osl_v2_0_assembly/meshes/Female_Micro_HDMI_Connector__RPi4ModelB_1.stl
0.02 x 0.0075 x 0.00352

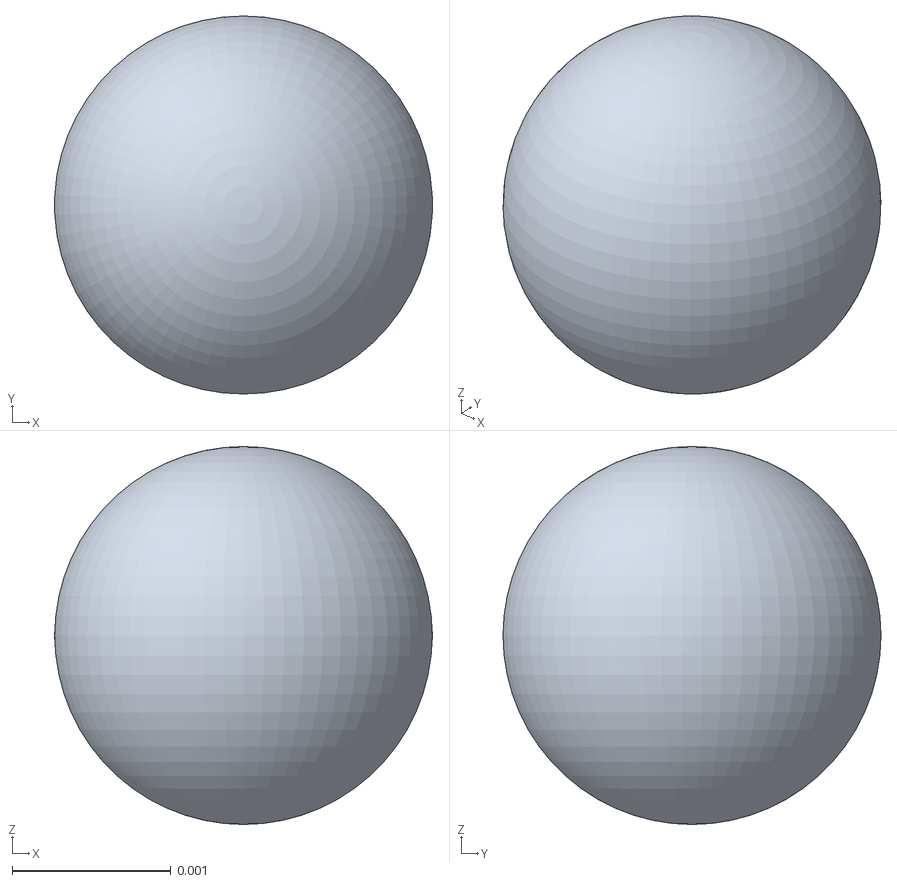
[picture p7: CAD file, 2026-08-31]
osl_v2_0_assembly/meshes/Part_18.stl
0.00238 x 0.00238 x 0.00238

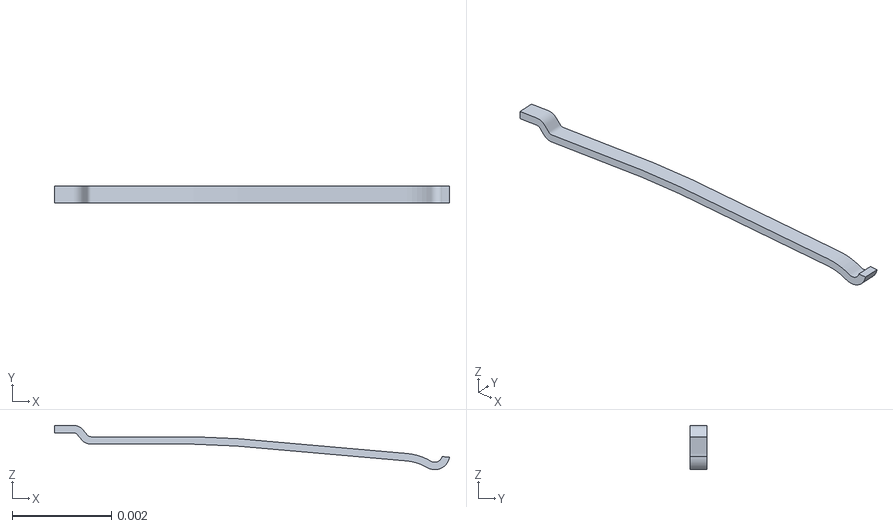
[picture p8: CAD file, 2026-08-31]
osl_v2_0_assembly/meshes/SD_Card_Slot__RPi4ModelB_9.stl
0.00795 x 0.00034 x 0.000892

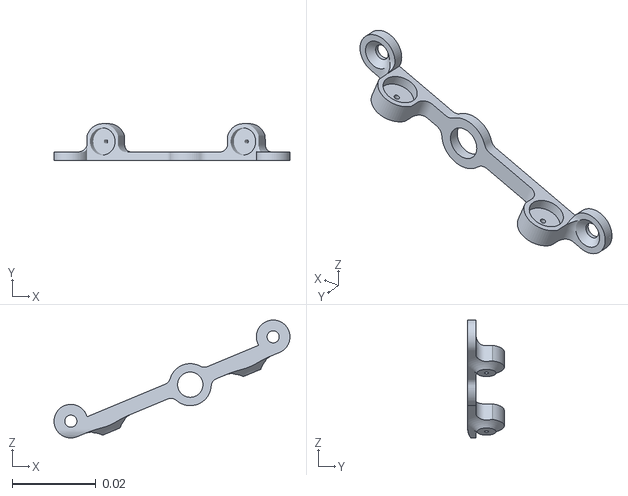
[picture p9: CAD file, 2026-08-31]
osl_v2_0_assembly/meshes/p_b2303_electronicsCoverAnkleHolderLeft.stl
0.0564 x 0.00874 x 0.0282

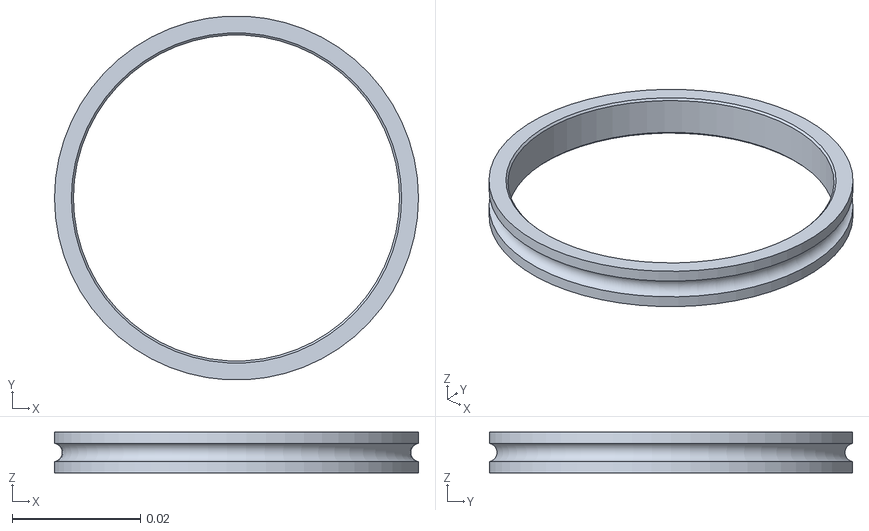
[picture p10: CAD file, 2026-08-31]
osl_v2_0_assembly/meshes/_6656K11_Ultra_Thin_Ball_Bearing_10.stl
0.0567 x 0.0566 x 0.00635

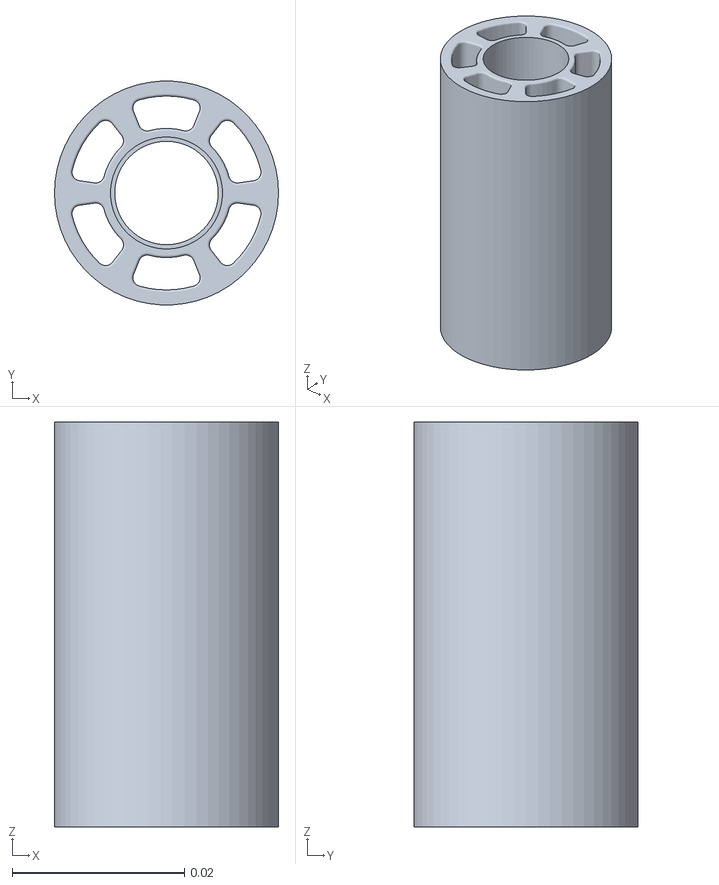
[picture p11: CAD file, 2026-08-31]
osl_v2_0_assembly/meshes/p_b0005idlerShell.stl
0.026 x 0.026 x 0.047

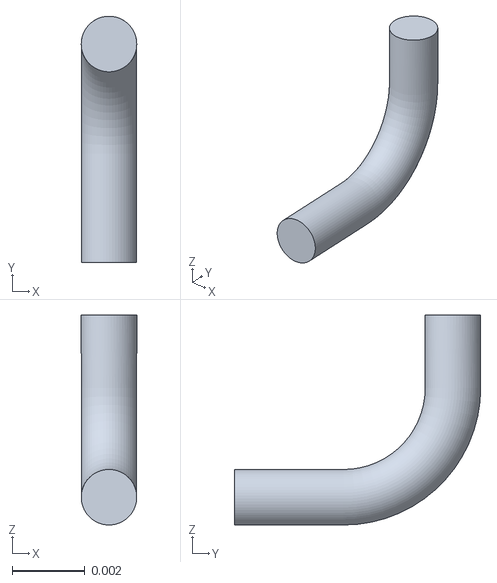
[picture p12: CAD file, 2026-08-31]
osl_v2_0_assembly/meshes/battery_connector_7.stl
0.00152 x 0.00676 x 0.00576

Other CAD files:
osl_v2_0_assembly/meshes/_2_54_mm_DUPONT_MALE_PIN_HEADER__IO__2X20__RPi4ModelB_16.stl
osl_v2_0_assembly/meshes/Part_22.stl
osl_v2_0_assembly/meshes/Camera_Connector__RPi4ModelB_5.stl
osl_v2_0_assembly/meshes/_2_54_mm_DUPONT_MALE_PIN_HEADER__IO__2X20__RPi4ModelB_33.stl
osl_v2_0_assembly/meshes/Display_Connector__RPi4ModelB_10.stl
osl_v2_0_assembly/meshes/BA30_P002_V04_CHASSIS_STEP.stl
osl_v2_0_assembly/meshes/BA30_P003_V04_REARCOV_STEP.stl
osl_v2_0_assembly/meshes/BA30_P004_V04_FRONTCOV_STEP.stl
osl_v2_0_assembly/meshes/Broadcom_BCM2711B0_CPU__RPi4ModelB.stl
osl_v2_0_assembly/meshes/Broadcom_BCM2711B0_CPU__RPi4ModelB_1.stl
osl_v2_0_assembly/meshes/Broadcom_BCM54213PE_Gigabit_Ethernet_Transceiver__RPi4ModelB.stl
osl_v2_0_assembly/meshes/Camera_Connector__RPi4ModelB.stl
osl_v2_0_assembly/meshes/Camera_Connector__RPi4ModelB_1.stl
osl_v2_0_assembly/meshes/Camera_Connector__RPi4ModelB_10.stl
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

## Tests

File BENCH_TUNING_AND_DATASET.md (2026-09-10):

# Bench controller tuning + Camargo dataset acquisition

**Scope of this report.** Answers A–F for the dataset-acquisition and controller-tuning
request. **No model was modified.** `models/osl_v2_bench.xml`, the KA_L1 fragment, all
MyoAssist code and the controller integration are byte-for-byte untouched; the only new
files are the three scripts and one figure listed in §Files. The human dataset has **not**
been used as a tracking input — instruction 11 is respected: every reference motion in the
gain sweep is synthetic.

**Two-tier evidence.** Every number below is tagged. `[MEASURED]` was read off a file,
`[COMPUTED]` was derived from measured values, `[PREDICTED]` came from the numpy
reproduction of the bench dynamics and is falsifiable by one Windows run, and
`[UNCONFIRMED]` still needs a machine I do not have. The sandbox I work in has **no
network access** (`data.mendeley.com` is not on the egress allowlist) and **no MuJoCo**, so
A, B and the real C must come from you running two commands. The scripts that produce them
are written, compiled and logic-tested. See §Commands.

---

## A. Confirmed dataset availability

**Status: three named, resolvable deposits identified; download not yet executed
`[UNCONFIRMED]`.** The Camargo et al. (2021) dataset is not embedded in the paper PDF
(`pdfdetach -list` reports zero attachments) `[MEASURED]`. It is distributed as three
Mendeley Data parts, cited in the paper's data-availability statement:

| Part | DOI | Note |
|---|---|---|
| 1 of 3 | `10.17632/fcgm3chfff.1` | |
| 2 of 3 | `10.17632/k9kvm5tn3f.1` | suffix printed across a line break in the PDF as `k9kvm5t-` / `n3f.1`; **verify by resolving before trusting** |
| 3 of 3 | `10.17632/jj3r5f9pnf.1` | |

Two secondary routes exist and should be treated as cross-checks, not the primary source:
the lab's own page at `epic.gatech.edu/opensource-biomechanics-camargo-et-al`, and the
Elsevier supplementary material attached to the article record.

`experiments/camargo_probe.py --check` resolves each DOI, prints the HTTP status and the
redirect target, and then attempts a file listing. Note honestly that the listing endpoint
it uses (`data.mendeley.com/public-api/datasets/{id}/files`) is marked UNVERIFIED in the
script and a failure there is non-fatal — DOI resolution is the load-bearing check, the
listing is a convenience. If the listing fails you will still see whether the deposits
exist and where they redirect, and you download through the browser.

One structural risk is worth flagging before you download 3 parts: the tables are stored as
MATLAB **`table` objects**. `scipy.io.loadmat` generally *cannot* decode these — they arrive
as opaque MCOS containers. The probe detects this case explicitly and prints the remediation
(a one-time CSV export from MATLAB or Octave) rather than failing with a confusing traceback.
If the files turn out to be v7.3 the probe reads them through `h5py` instead. This is the
single most likely thing to cost you an hour, so it is checked first.

## B. Selected subject, trial, files, columns, units

**Subject `AB19` `[MEASURED from paper Table 1]`** — male, 1.70 m, 68.0 kg. Chosen because
he sits essentially on the cohort mean (1.70 ± 0.07 m, 68.3 ± 10.83 kg), so nothing in the
first experiment depends on an atypical body. Backups, in order, are `AB27` (near-identical
anthropometry, independent subject) and `AB20`. Subject IDs skip AB22, AB26 and AB29, so do
not read a gap as a missing download. The fallback rule from instruction 2 is implemented in
the probe, not left to judgement: if AB19 has no `levelground` trial carrying a finite knee
moment, the probe says so and names the next `PREFERRED` subject that does.

**Trial condition:** `levelground`, self-selected **normal** speed only (cohort 1.17 ± 0.21
m/s; the slow/fast conditions are 0.88 and 1.45 m/s). One subject, one condition, per
instructions 3 and 4.

**Layout `[MEASURED from the paper's description]`:** `subject / date / mode / sensor`, e.g.
`AB19/<date>/levelground/ik/*.mat`. The `sensor` level is where the variables live:
`ik` (inverse kinematics → joint angles), `id` (inverse dynamics → moments and powers),
`gcRight` (gait cycle / heel-strike percentage), `conditions` (speed and condition labels),
`gon` (goniometer, 1000 Hz, useful as an independent sign check).

**Expected file and column mapping.** These are the names to *look for* — they are the
OpenSim gait2392 conventions the pipeline implies, and they are **`[UNCONFIRMED]` until the
probe prints the real headers.** Nothing downstream hard-codes them:

| Quantity | Expected file | Expected column | Expected unit |
|---|---|---|---|
| right knee angle | `levelground/ik/*.mat` | `knee_angle_r` | deg |
| right knee moment | `levelground/id/*.mat` | `knee_angle_r_moment` | N·m/kg (mass-normalised) |
| right knee power | `levelground/id/*.mat` | `knee_angle_r_power` | W/kg (mass-normalised) |
| time | every table | `Header` | s (200 Hz for `ik`/`id`) |
| gait phase | `levelground/gcRight/*.mat` | `HeelStrike` | % 0–100 |
| walking speed | `levelground/conditions/*.mat` | `Speed` / label column | m/s |
| subject mass | paper Table 1 (`SubjectInfo` if present) | — | kg (68.0 for AB19) |

Two things about this table matter more than the names. First, **units are inferred from the
data, not from the paper** (instruction 6): `infer_unit()` distinguishes degrees from radians
by numeric range, mass-normalised from absolute moment by magnitude, percent from fraction,
and — importantly — flexion-positive from flexion-negative. That last one is a real trap:
gait2392's `knee_angle_r` is flexion-*negative* while the paper's figures are
flexion-*positive*, so the stored sign must be checked against landmarks (stance flexion
peak ~15–20° near 15 % GC, swing peak ~60–65° near 70–73 %, toe-off ~60–62 %) and against
the 1000 Hz goniometer. Getting this wrong would silently invert the whole experiment.

Second, **gait phase is pre-computed per sample** `[MEASURED from the paper]` — the authors
interpolate linearly between right heel strikes, where heel strike is detected as zero
linear velocity of the heel marker. So instruction 7 resolves to "use it directly"; the
heel-strike-to-heel-strike reimplementation is coded as a fallback only and should not be
needed. The probe reports which branch applies.

One coverage constraint will bite during stride selection: ground reaction force was recorded
only "during certain representative steps," and "gait cycles without ground reaction force
data were excluded from moment and power analyses." Kinematics are therefore available on
far more strides than kinetics, and strides must be filtered to those with a non-null knee
moment. The probe counts these per trial. No figure is digitized, and specifically not
Figure 6, which is a 22-subject average (instruction 8).

## C. Gain sweep results

**Status: `[PREDICTED]`, not yet run in MuJoCo.** The sandbox has no MuJoCo, so rather than
leave C empty I reproduced in numpy the *exact* dynamics MuJoCo integrates for this model.
That reproduction is legitimate here for a specific structural reason: `knee_prox` carries no
freejoint, so the bench is welded to the world, and with the ankle held at its keyframe the
knee is a genuine single-DOF pendulum. The equation of motion is then fully determined by
values authored in the MJCF, with nothing fitted:

```
I_eff * qdd = tau_act + tau_gravity(q) - b*qd - frictionloss*sign(qd)
tau_act     = clip(kp*(ref - q) - kv*qd, -142.2, +142.2)
```

with `[COMPUTED from the MJCF]` `I_eff = 0.251998 + 0.01 armature = 0.261998 kg·m²`,
`b = 0.3 N·m·s/rad`, `frictionloss = 0.4 N·m`, `m·g·d = 8.8529 N·m`. Running
`experiments/run_gain_sweep.py` on Windows should agree with the tables below to within the
integrator difference (semi-implicit Euler here vs MuJoCo's), and any disagreement larger
than a few percent is a finding in itself, not a nuisance.

**Gains, from ζ = 0.7 crediting the damping the model already has.** Solving
`ζ = (kv + b_joint) / (2√(kp·I_eff))` for `kv` rather than ignoring the authored
0.3 N·m·s/rad — which matters at low kp, where 0.3 is 6 % of the total:

| kp (N·m/rad) | kv (N·m·s/rad) | ω_n (Hz) | f_−3dB (Hz) | lag @0.9 Hz | lag (%GC) | friction deadband |
|---|---|---|---|---|---|---|
| 60 | 5.251 | 2.409 | 2.43 | 96.6 ms | 8.69 | 0.382° |
| 200 | 9.834 | 4.397 | 4.44 | 51.4 ms | 4.63 | 0.115° |
| **600** | **17.253** | **7.616** | **7.68** | **29.4 ms** | **2.65** | **0.038°** |
| 2000 | 31.747 | 13.905 | 14.03 | 16.0 ms | 1.44 | 0.011° |

**Tracking, five synthetic references, all four gains `[PREDICTED]`.** Errors in degrees,
torque in N·m, `%auth` against the authored ±142.2 N·m:

| reference | kp | RMS err | peak err | ss err | peak τ | %auth | %sat |
|---|---|---|---|---|---|---|---|
| step 10° | 60 | 1.141 | 1.457 | 1.136 | 10.47 | 7.4 | 0.0 |
| step 10° | 200 | 0.343 | 0.347 | 0.347 | 34.91 | 24.5 | 0.0 |
| step 10° | 600 | 0.131 | 0.131 | 0.131 | 104.72 | 73.6 | 0.0 |
| step 10° | 2000 | 0.051 | 0.051 | 0.051 | 142.20 | 100.0 | 0.6 |
| step 45° | 60 | 4.991 | 5.206 | 5.206 | 47.12 | 33.1 | 0.0 |
| step 45° | 200 | 1.710 | 1.737 | 1.737 | 142.20 | 100.0 | 0.2 |
| step 45° | 600 | 0.635 | 0.638 | 0.635 | 142.20 | 100.0 | 1.7 |
| step 45° | 2000 | 0.184 | 0.184 | 0.184 | 142.20 | 100.0 | 4.9 |
| sine 0.9 Hz 0–60° | 60 | 10.815 | 18.083 | 6.027 | 5.30 | 3.7 | 0.0 |
| sine 0.9 Hz 0–60° | 200 | 6.074 | 9.624 | 3.220 | 5.61 | 3.9 | 0.0 |
| **sine 0.9 Hz 0–60°** | **600** | **3.523** | **5.361** | **1.710** | **5.75** | **4.0** | **0.0** |
| sine 0.9 Hz 0–60° | 2000 | 1.929 | 2.847 | 0.863 | 5.80 | 4.1 | 0.0 |
| min-jerk 60°/0.3 s | 60 | 13.389 | 32.132 | 6.543 | 12.50 | 8.8 | 0.0 |
| min-jerk 60°/0.3 s | 200 | 7.348 | 19.638 | 2.082 | 17.07 | 12.0 | 0.0 |
| **min-jerk 60°/0.3 s** | **600** | **4.145** | **11.394** | **0.702** | **19.28** | **13.6** | **0.0** |
| min-jerk 60°/0.3 s | 2000 | 2.218 | 6.144 | 0.210 | 19.72 | 13.9 | 0.0 |
| chirp 0.2–8 Hz | 60 | 8.494 | 16.302 | 6.625 | 14.23 | 10.0 | 0.0 |
| chirp 0.2–8 Hz | 200 | 7.389 | 13.905 | 7.336 | 37.53 | 26.4 | 0.0 |
| chirp 0.2–8 Hz | 600 | 5.805 | 12.733 | 6.994 | 80.82 | 56.8 | 0.0 |
| chirp 0.2–8 Hz | 2000 | 3.419 | 8.230 | 4.554 | 111.55 | 78.4 | 0.0 |

Figure: `experiments/gain_sweep_prediction.png`.

Three results in that table are worth more than the rest.

**The steps are the wrong discriminator, and the table shows why.** A step is infinitely
fast, so it asks for infinite torque; the 45° step saturates the authored limit at *every*
gain from 200 up, and the 10° step reaches 100 % authority at kp=2000. Saturation percentages
in the step rows are artifacts of the input, not statements about the leg. Keep the steps as
diagnostics — they are how you see gravity droop and overshoot cleanly — but do not select a
gain on them.

**On smooth references, the residual error is almost pure phase lag.** The linearised
closed-loop magnitude |H| at 0.9 Hz is ≈ 1.000 at all four gains, yet the RMS error still
falls from 10.8° to 1.9°. That error is therefore timing, not amplitude attenuation — visible
in the top-right panel of the figure as an error trace in quadrature with the reference
rather than in phase with it. This has a practical consequence for later: lag can be removed
essentially for free by advancing the reference in time or adding a feedforward term, whereas
buying the same reduction by raising kp costs torque and physical plausibility. Do not raise
kp to fix a problem that is really a time shift.

**kp=60 — the authored value — is not merely imprecise, it is qualitatively wrong here.** Its
2.41 Hz closed-loop bandwidth sits *below* the frequency content of the reference it must
track, and gravity contributes 8.85 N·m/rad, which is 15 % of kp at kp=60 but only 0.4 % at
kp=2000. So at kp=60 gravity is a first-order part of the loop, not a disturbance: it drags
steady state 5.2° off target at 45° flexion and shows up as *negative* overshoot on the step.
The passive pendulum frequency about the knee is 0.925 Hz — which is to say, the leg's own
unforced dynamics sit right on top of the gait fundamental. A servo that soft does not
command the trajectory so much as negotiate with it.

## D. Recommended gain pair

> **kp = 600 N·m/rad, kv ≈ 17.25 N·m·s/rad** (ζ = 0.7), set at runtime on the knee actuator.

Five reasons, in the order they matter.

Bandwidth first: 7.68 Hz is roughly 8× the 0.9 Hz gait fundamental and sits above the ~5–6 Hz
content of a real knee trajectory, so the loop is not the bottleneck on the reference. kp=200
at 4.44 Hz is marginal against that content, and kp=60 at 2.43 Hz is simply inside it.

Accuracy is sufficient and honest: 3.52° RMS with 5.36° peak on the gait-rate sinusoid, and
0.70° steady-state on the fast min-jerk excursion. Against a 60° swing excursion that is
~6 % RMS, and most of it is the removable phase lag discussed above.

Torque demand stays in a defensible band: 13.6 % of authority worst case on a smooth
reference, with **zero** saturation on any smooth reference. Nothing about the result depends
on hitting a limit.

The nonlinearities stop mattering: gravity droop falls from 5.2° at kp=60 to 0.64°, and the
Coulomb friction deadband from 0.382° to 0.038° — an order of magnitude below anything the
experiment will resolve.

And the honest reason to stop at 600 rather than take 2000: kp=2000 buys about 1.6° more RMS
accuracy, and charges 78.4 % of torque authority on the 8 Hz chirp, 10.5 % overshoot once
saturated, and a joint stiffness 6–20× any physically plausible OSL impedance. That last cost
is the real one. A gain that only works because the simulator has no bandwidth limit,
backlash or transmission compliance produces a result that will not transfer to the hardware,
and transfer is the point of the twin. kp=600 is the largest gain that is still arguable as a
physically implementable impedance.

Numerical stability is *not* what limits this: `ω_n·dt = 0.044` even at kp=2000, comfortably
stable. The binding constraints are torque saturation and physical plausibility, which is a
better position to be in — it means the choice is a modelling argument, not a solver artifact.

**This is controller tuning, not a change to the physical OSL model.** kp and kv are
properties of the tracking controller. They are written only into the compiled `mjModel` at
runtime; `models/osl_v2_bench.xml` is never opened for writing. That claim is auditable
rather than asserted: section [8] of `experiments/run_gain_sweep.py` re-reads `forcerange` and
`ctrlrange` after the entire sweep and fails the run if either differs from the authored
values, and it re-runs one configuration to confirm bit-identical output. Mass, inertia,
geometry, joint limits, damping, frictionloss and armature are untouched throughout.

## E. Expected torque demand vs. OSL torque authority

`[PREDICTED]`, knee, against the authored ±142.2 N·m:

| Demand | Peak τ | % authority |
|---|---|---|
| 0.9 Hz gait-rate sinusoid, 0–60° | 5.30–5.80 N·m | 3.7–4.1 % |
| min-jerk 60° in 0.3 s (fastest realistic excursion) | 12.50–19.72 N·m | 8.8–13.9 % |
| loose non-simultaneous upper bound (I·α + b·ω + gravity + friction) | 27.63 N·m | 19.4 % |
| earlier peak-swing estimate | 33.5 N·m | 23.5 % |

The conclusion to report is that **torque authority was never the limiting factor on any
smooth reference**; saturation appears only on artificial step inputs. Because demand sits
below a quarter of authority, the idealizations in the torque model (no torque–speed curve,
no thermal state, no backlash, no transmission compliance) are second-order for *this*
experiment. That is a statement about this bench task, not a general endorsement.

Two caveats must travel with any use of these numbers.

**The fixed base is the central scientific caveat.** `knee_prox` is welded to the world, so
the actuator fights only `I·α + m·g·d·sin θ + b·ω + frictionloss` — it does **not** carry body
weight. Simulated bench torque is therefore *not* comparable to a human knee moment in
stance, where the moment is dominated by the body weight the bench never bears. Kinematic
comparison is valid across 0–100 % of the cycle; torque comparison is loosely valid only in
swing (~60–100 %). Shade and label 0–60 % on every torque plot, and never extrapolate a bench
torque agreement into a claim about stance.

**Required wording whenever the torque authority is described.** `OpenSourceLeg_KA_L1` models
gearbox-related torque authority via knee gain 49.4, ankle 58.4, and ctrlrange ±2.88
motor-shaft torque, giving knee ≈ ±142.27 N·m and ankle ≈ ±168.19 N·m. It does **not** model
the motor as an electrical system, nor current, voltage, torque–speed curve, efficiency,
thermal state, backlash, transmission compliance, device-authored rotor inertia, or actuator
bandwidth/latency. Therefore do **not** describe this as a full motor/gearbox simulation. The
correct wording is: *"the model represents the available joint torque authority derived from
the motor/gear relationship, but idealizes the torque production."* Also do not call the
49.4 / 58.4 / 30 A / 0.096 N·m/A values experimentally verified hardware values — they are
recoverable model derivation values from repository history unless a hardware datasheet
confirms them.

## F. Exact next step for the human gait-tracking experiment

Not started, by instruction. The next step is a single gate, then one script.

**The gate:** run the two commands in §Commands. Item A becomes confirmed or it does not;
item B's expected column names are replaced with real ones; item C's predictions are replaced
with MuJoCo output. If the MuJoCo sweep disagrees with the prediction by more than a few
percent, that disagreement is the next thing to investigate and the gait experiment waits.

**Then, and only then, the tracking experiment**, whose shape is now fully constrained by the
above: take AB19's `levelground` normal-speed strides, keep only those with a finite knee
moment, resample the pre-computed 0–100 % gait phase onto the 0.5 ms bench timestep, verify
the flexion sign against the landmark angles before anything else, clamp the reference into
the model's authored `[−5°, +120°]` ROM and *report* any clamping rather than silently
absorbing it, drive `ctrl` with that reference at kp=600 / kv=17.25, and compare reference
angle, simulated angle, tracking error, torque and angular velocity — with the 0–60 % stance
region shaded on torque plots and excluded from any torque claim.

Two decisions are deferred to that point and should be made explicitly rather than by
default, since both are physics assumptions: whether to advance the reference in time (or add
feedforward) to remove the ~29 ms phase lag, and whether to cross-check on `KA_L1`, whose
`[0°, +120°]` hard stop would clip the terminal-stance hyperextension that our `[−5°, +120°]`
range admits. That clipping difference is exactly the sort of thing that looks like a
controller result and is not one.

---

## Commands

Both are read-only with respect to models. Run from the `osl-mujoco` root.

**1. The gain sweep (uses `osl-mujoco`'s existing venv — mujoco 3.12 + numpy is all it
needs; that venv is not modified):**

```
.venv\Scripts\python.exe experiments\run_gain_sweep.py
```

Writes `build/gain_sweep/gain_sweep_trace.csv` and `gain_sweep_metrics.csv`. It runs nine
preflight checks and **refuses to sweep** if the model does not match expectations, so a
non-zero exit code means a real discrepancy, not a crash. Exit code equals the failure count,
matching `tools/validate_mjcf.py`.

**2. The dataset probe (needs a separate analysis venv — `osl-mujoco/.venv` deliberately has
no scipy/requests/h5py and must not be modified):**

```
py -3 -m venv .venv-analysis
.venv-analysis\Scripts\python.exe -m pip install numpy scipy h5py requests
.venv-analysis\Scripts\python.exe experiments\camargo_probe.py --check
.venv-analysis\Scripts\python.exe experiments\camargo_probe.py --probe <unzip-root> --subject AB19
```

`--check` tests availability (item A). `--probe` prints the seven sections that answer item B
off the real files. Optional: `experiments\gain_sweep_analytic.py --no-plot` in the analysis
venv reproduces the §C prediction tables for side-by-side comparison.

## Files

Created, all new:

- `experiments/run_gain_sweep.py` — the runtime-only MuJoCo sweep (originally written as one
  file, `experiments/gain_sweep_bench.py`; the reusable half now lives in `oslbench/`, see
  `docs/REFACTOR_MAP.md`). numpy + mujoco + stdlib
  `csv` only, so it runs in the existing venv. Logs 18 columns per step including torque
  recorded three independent ways (the `knee_tau` actuatorfrc sensor, `data.actuator_force`,
  and the unclamped analytic `kp*(cmd−q) − kv*qd`) so that the gain injection itself is
  cross-checked rather than trusted.
- `experiments/camargo_probe.py` — availability check + structure/column/unit discovery.
  Discovers rather than assumes; every guess is printed as a guess; averages nothing.
- `experiments/gain_sweep_analytic.py` — the numpy prediction and the figure.
- `experiments/gain_sweep_prediction.png` — the four-panel figure.

Modified: none. Not touched: `models/osl_v2_bench.xml`, the Onshape URDF export, the KA_L1
fragment, all MyoAssist code, the controller integration, `osl-mujoco/.venv`.

Tests run: `py_compile` on all three scripts (clean); an AST arity sweep (clean); the probe's
discovery path exercised end-to-end against a synthetic dataset tree in the correct
`subject/date/mode/sensor` layout, where it correctly located AB19, listed the sensor folders,
read every table, and inferred `knee_angle_r` → "DEGREES, flexion-POSITIVE",
`knee_angle_r_moment` → "N·m/kg (mass-normalised)", `knee_angle_r_power` → "W/kg",
`HeelStrike` → "PERCENT 0-100", `Header` → "SECONDS, dt = 5.000 ms → 200.0 Hz, monotonic",
and detected gait phase at `gcRight/HeelStrike`. The MuJoCo sweep has **not** been executed —
no MuJoCo in my sandbox.

One methodological note on that last test: passing against a synthetic tree proves the
discovery logic is correct, not that the real dataset matches my expectations. Those are
different claims, and only your run collapses the second one.

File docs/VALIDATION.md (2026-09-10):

# Validation: does the reorganised code still produce the validated result?

A reorganisation that changes the numbers is not a reorganisation, it is a new experiment.
This file records how that is checked, what the check has established, and the one part of
it that still has to be run on the Windows machine.

## The claim being defended

The benchmark result, produced by the original single-file implementation
(`experiments/bench_track_ab19.py`, now deleted; recoverable from git at `0cd33a5`):

| Metric | Value |
| --- | --- |
| RMS tracking error | 4.361613372292228 ° |
| peak tracking error | 9.090662089393883 ° |
| mean absolute error | 3.2798529494340207 ° |
| peak actuator torque | 16.004120587370423 N·m |
| torque authority used | 11.25465582796795 % |
| torque saturation | 0.0 % |
| peak knee velocity | 5.055899819703143 rad/s |
| steps | 2410 |
| reference clipped into ROM | 0 steps |

## How the comparison works

The old implementation's **actual output files** were frozen, not its summary numbers:

```
tests/oracle/bench_track_ab19.csv          2410 rows x 21 columns -- the full trace
tests/oracle/bench_track_ab19_metrics.csv  every metric, the audit fields, all 5 flags
```

`experiments/verify_against_oracle.py` re-runs the pipeline as it stands today, then
compares every column of every one of the 2410 rows, and every metric, against those files.
So the comparison is not "the headline numbers still look right" — it is a row-by-row,
column-by-column identity check on reference angle, actual angle, error, velocity, command,
torque, unclamped torque, percent authority, saturation flag and power.

The oracle lives in `tests/`, not `build/`, on purpose: `build/` is gitignored and is
overwritten by every run, so an oracle stored there would be destroyed by the first re-run.

**Tolerance.** Each column is compared at the resolution the CSV is *written* at — a
disagreement smaller than the last printed digit is not detectable in the file at all, so
that is the only defensible tolerance for a file comparison. In practice this is 5e-7 for
the degree and torque columns and 5e-9 for the radian columns, and the saturation flag must
match exactly. Metrics are compared at 1e-9 relative. The expectation is not "within
tolerance" but *bit-identical*: the reorganisation moved code between files and did not
change the order of a single MuJoCo call.

## The command

```powershell
.\.venv\Scripts\python.exe experiments\verify_against_oracle.py
```

It exits non-zero on any disagreement and prints which column or metric differs, at which
step, by how much. `--update-oracle` re-freezes the oracle and should only ever be used
deliberately, after a change that is *intended* to move the numbers.

## What has been established, and by what

**The reference half of the pipeline is confirmed identical.** This was checked by running
the current code against the oracle with the physics deliberately replaced by
`tests/stub_mujoco.py`, a small 2-DOF stand-in plant. Under that substitution the columns
that cannot depend on the plant came out matching the oracle exactly —

`time_s`, `gait_phase_percent`, `ref_rad`, `ref_deg`, `ref_vel_rad_s`, `ctrl_rad`,
`saturated`, `human_knee_angle_deg`, `human_knee_moment`, `human_knee_power`, every
`ref_*` audit field, and all five audit flags in their original order

— while the eleven plant-dependent columns and fifteen plant-dependent metrics differed, as
they must. That is a useful result in both directions: it confirms that CSV loading, column
validation, the audit, the cubic-spline resample, the phase computation, the ROM clip and
the writer all survived the move byte-for-byte, and it confirms that the comparison has
teeth rather than passing trivially. (The stub landed about 1.9 % away on RMS error —
4.2791° against 4.3616° — which is a sane ballpark and unmistakably not the experiment.)

**The control law and the wiring are confirmed by the test suite.** `tests/run_tests.py`,
44 tests, checks the PD equation against arithmetic performed independently inside the
test, that `KD` really is the ζ = 0.7 value for `KP = 600`, that both saturations fire in
both directions and that their flags agree with their values, that the four gain writes
reach the compiled model while `forcerange` and `ctrlrange` are left untouched, that the
step identity `tau_actuator == controller.torque(q_ref, q_pre, qdot_pre)` holds, and that
the reference contract holds (101 rows, phase in `[0, 100)`, period 1.2050 s, 2410 uniform
resamples). Result: 43 passed, 0 failed, 1 skipped — the skip is deliberate, a guard that
refuses to let a stub run be mistaken for validation.

**The protected artefacts are confirmed unchanged**, by sha256 asserted in the tests:

```
models/osl_v2_bench.xml            c417e691ff90a6f4a47ef581e6caaa341b0e1c829038f6d3e6740927ae69053d
build/AB19_knee_gait_reference.csv 83fed583b80c61c5bcd7978f2f2dd0870fe3c1efa25db68dbe9606b20da8a00d
```

No MyoAssist or `OpenSourceLeg_KA_L1` file was read or written by any of this, which the
tests also check by parsing every Python file in the repository and looking for such an
import or path.

## What still has to be run

**The full oracle comparison has not been executed against real MuJoCo.** The environment
this refactor was carried out in has no MuJoCo installed and no network to install it, so
the plant-dependent half of the comparison — the eleven columns and fifteen metrics that
depend on the physics engine, including every headline number in the table at the top of
this file — is checked by a script that has been written, exercised and shown to fail
correctly, but not yet seen to pass.

That gap closes with one command, run on the Windows machine in `.venv`:

```powershell
.\.venv\Scripts\python.exe experiments\verify_against_oracle.py
```

Until that has been run, the honest statement is: *the reference pipeline is proven
identical, the control law is proven correct, the artefacts are proven unchanged, and the
physics is expected to be bit-identical because no MuJoCo call moved — but expected is not
measured.*

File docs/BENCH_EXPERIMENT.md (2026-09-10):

# The bench experiment, question by question

This is the document to read before judging the result. It answers, in order: what is
being simulated, what the human data is, what the controller is, what happens on each
0.5 ms step, what is measured, and — the part that matters most — what this experiment
does **not** establish.

If you only want to find a file, read `docs/CODE_MAP.md` instead. If you want to run it,
the Quick Start is in `README.md`.

## What model is being simulated?

`models/osl_v2_bench.xml`: the Open-Source Leg V2, generated from the official Onshape
CAD export by `tools/build_mjcf.py`, welded to the world at the knee-proximal segment.
Three bodies (`knee_prox`, `shank`, `foot`), two hinges (knee, ankle), two position
actuators, and the sensor set the real leg reports — joint encoders, actuator torque, two
IMUs and a six-axis load cell.

Mass, centre of mass and inertia of each segment come from the exact mesh volume
(divergence theorem over each closed triangle mesh) times a density assigned per part
family. Both hinge anchors come from the CAD, not from a choice: knee at
`(0.00065, 0, 0.19311)`, ankle at `(0, 0, −0.13873)`, 331.84 mm apart. Range of motion
comes from this export's own hard stops: knee −5° to +120°, ankle −30° to +20°.
`scripts/check_model.py` holds MuJoCo to those numbers on every run rather than merely
asking whether the file compiled.

Because the base is welded, the model has exactly two degrees of freedom (`nq = nv = 2`),
and the knee's is the only one that moves during the experiment.

## Why this model, and not something simpler or something bigger?

Simpler would be a rod and a point mass. That was rejected because the whole reason the
CAD model exists is to get the segment inertia right, and a generic rod would put the
answer back to being a guess.

Bigger would be a whole-body walking model. That was also rejected, but only *for this
experiment*, and for one reason: on a fixed base, exactly one mass property of the leg
can affect the answer, and that makes the result interpretable. With the proximal segment
welded, the knee sees an effective inertia of

```
I_eff = I_body + armature = 0.251998 + 0.010 = 0.261998 kg·m²
```

plus joint damping 0.3 N·m·s/rad, joint friction 0.4 N·m and a gravity moment of
8.8529 N·m at full extension. Nothing else in the model can change the trajectory. So
when the tracking error comes out at 4.36° we can say precisely what produced it — and,
as it turns out, show that 90 % of it is servo phase lag rather than a modelling defect.
On a walking model the same number would be entangled with ground contact, body weight
and balance, and there would be no way to attribute it.

The bench is therefore the *first* experiment, not the intended final one.

## What human data is being tracked?

`build/AB19_knee_gait_reference.csv`: one complete right-leg gait cycle from subject AB19
of the Camargo et al. open lower-limb dataset (Georgia Tech), trial
`levelground / ccw / normal / 01_01`. 101 samples spanning 0 to 100 % of the gait cycle,
which at this subject's cadence is a period of 1.2050 s.

`oslbench/reference.py` loads five columns verbatim, audits them, and resamples the knee
**angle** column onto the model's 0.5 ms grid with a natural cubic spline — 101 samples
become 2410 steps. The spline reproduces every original measured sample to about
1e-14 degrees, so resampling adds no error at the data points; only between them is it an
interpolation, which is unavoidable for any 100 Hz-equivalent recording driven at 2 kHz.

Gait phase is not interpolated. It is computed analytically as
`100 × (t mod T) / T`, so it stays in `[0, 100)` by construction and can never drift.

## Why AB19?

Because the dataset publishes it in a form that needs no assumptions: a single named
subject, a single named trial, level ground at normal speed, one clean right-leg cycle.
An averaged or normalised "typical" gait curve would have been smoother and less honest —
it would have hidden which subject and which trial produced it, and there would be nothing
to go back to if a column turned out to be wrong.

Which matters, because a column *did* turn out to be wrong. See "What is wrong with the
data" below.

## What is the controller?

A joint-space PD position controller. In full, from `oslbench/controller.py`:

```python
error = q_ref - q                       # rad      reference minus measured angle
tau   = Kp * error - Kd * qdot          # N.m      the requested torque
```

with `Kp = 600.0` N·m/rad and `Kd = 17.253` N·m·s/rad, and two saturations applied around
it:

1. **The command is clipped into the joint's range of motion** before the error is formed,
   so the controller can never chase an angle the hardware cannot reach. Measured on the
   AB19 reference: **0 of 2410 steps** were clipped — the human trajectory lies entirely
   inside the mechanism's ROM.
2. **The requested torque is clamped to the actuator's `forcerange`**, ±142.2 N·m at the
   knee. Measured: **0.00 % of steps** saturated, with a peak request of 16.00 N·m, which
   is 11.25 % of the available authority.

There is no integral term, no feedforward, no gain scheduling and no impedance law. That
is deliberate: this is a baseline whose failure mode should be diagnosable, not a
candidate final controller.

## What are Kp and Kd, physically?

`Kp` is a rotational stiffness in N·m per radian of tracking error — how hard the actuator
pulls toward the commanded angle. `Kd` is a rotational damping in N·m per rad/s of joint
velocity — it opposes motion, which is what stops the stiffness from causing overshoot and
ringing.

Together with the plant they set the closed-loop behaviour of a second-order system:

```
natural frequency   ω_n = sqrt(Kp / I_eff)            = sqrt(600 / 0.261998) = 47.86 rad/s ≈ 7.6 Hz
damping ratio       ζ   = (Kd + b_joint) / (2 sqrt(Kp · I_eff))
```

Note that the joint's own damping `b_joint = 0.3` counts toward ζ. Ignoring it is a
common way to end up slightly under-damped.

## Why *these* values of Kp and Kd?

`Kd` is not tuned at all — it is derived. Given a target damping ratio, rearranging the
expression above gives

```python
# oslbench/controller.py:56
Kd = 2 * zeta * sqrt(Kp * I_eff) - b_joint
```

At ζ = 0.7 — the standard choice for a servo that should settle fast without overshooting
— and Kp = 600, this gives Kd = 17.253. So there is exactly one free parameter in this
controller, and `Kd` follows from it.

`Kp = 600` came from a sweep, not a preference. `experiments/run_gain_sweep.py` runs the
same plant and the same control law across a range of Kp with Kd re-derived at each point,
and `BENCH_TUNING_AND_DATASET.md` records the reasoning. The short version: below about
Kp = 300 the loop is too slow to follow the swing-phase velocity peak; above about
Kp = 600 the tracking error stops improving, because what remains is not stiffness-limited.

That last claim is measured rather than asserted. `oslbench/metrics.py:lag_diagnostic`
searches for the time shift that best aligns the simulated trajectory with the reference,
and finds **29.5 ms** — about 2.4 % of the gait cycle. Removing that shift drops the RMS
error from 4.3616° to 0.4333°, i.e. **90.1 % of the tracking error is pure phase lag.**
Raising Kp to chase a lag is the wrong fix; advancing the reference in time, or adding a
feedforward term, is the right one. Neither has been done, because this run is the
baseline they would have to be measured against.

## What exactly happens on each 0.5 ms step?

`oslbench/simulation.py:179`, in order:

1. Look up the reference angle for this step, `q_ref[k]`, from the resampled array.
2. Read the current measured state from the sensors: `q` (knee angle, rad) and `qdot`
   (knee velocity, rad/s).
3. Clip `q_ref` into `ctrlrange` and write it to `data.ctrl[knee]`. Note that for a MuJoCo
   position actuator `ctrl` **is an angle in radians**, not a torque.
4. Call `mujoco.mj_step`. Inside that call MuJoCo evaluates the actuator, which is
   configured so that its output is exactly `Kp*(ctrl − q) − Kd*qdot`, clamps the result to
   `forcerange`, applies it to the knee hinge, and integrates the two-DOF plant forward by
   0.5 ms against gravity, joint damping and joint friction.
5. Read back what happened: the new `q`, `qdot`, and the actuator torque that was applied.
6. Hand all of it to the logger as one row.

Steps 1–3 and 6 are Python. Step 4 is entirely MuJoCo. The controller runs *inside* the
simulation loop, once per step, at 2 kHz — not once per frame and not offline.

One detail worth stating because it looks like a bug and is not: after `mj_step`, MuJoCo's
`actuator_force` reports the torque that was used to *take* the step, i.e. evaluated on the
pre-step state. The logged `tau_unclamped` column is evaluated on the post-step state.
They are close but not equal, and the identity test in `tests/test_oslbench.py` compares
the actuator's torque against the control law evaluated on the pre-step state, which is
the honest comparison.

## How does the controller's torque reach the physics?

Through the compiled model, at runtime. A MuJoCo `position` actuator computes

```
tau = gainprm[0]*ctrl + biasprm[0] + biasprm[1]*q + biasprm[2]*qdot
```

so writing `gainprm[0] = Kp`, `biasprm = [0, −Kp, −Kd]` makes MuJoCo itself evaluate
`Kp*(ctrl − q) − Kd*qdot`. That is four array writes, in
`oslbench/controller.py:116 write_to_model`.

Two consequences worth noting. `models/osl_v2_bench.xml` is never edited — the XML's
authored `kp = 60` placeholder servo is overwritten in memory, and the file on disk is
byte-for-byte unchanged (the tests assert its sha256). And `forcerange` and `ctrlrange`
are deliberately *not* written, so the authored torque authority and ROM keep bounding
everything the controller can do.

## What is measured?

Per step, 21 columns into `build/bench_track_ab19/bench_track_ab19.csv`: time, gait phase,
reference angle and velocity, commanded angle, measured angle and velocity, tracking
error, actuator torque, unclamped requested torque, torque as a percentage of authority, a
saturation flag, mechanical power, the ankle's held angle, and the three human columns
carried through verbatim.

From that, `oslbench/metrics.py` computes the summary. The validated result:

| Metric | Value |
| --- | --- |
| RMS tracking error | 4.3616° |
| peak tracking error | 9.0907° |
| mean absolute error | 3.2799° |
| peak actuator torque | 16.0041 N·m |
| torque authority used | 11.25 % of ±142.2 N·m |
| torque saturation | 0.00 % of steps |
| reference clipped into ROM | 0 of 2410 steps |
| peak knee velocity | 5.0559 rad/s (reference peak 5.1077) |
| servo lag | 29.5 ms = 2.45 % of the cycle |
| RMS error with the lag removed | 0.4333° (so 90.1 % of the error is lag) |

`experiments/verify_against_oracle.py` re-runs the experiment and compares all 21 columns
and all metrics against a frozen copy in `tests/oracle/`, so these numbers are defended by
a check rather than by a note in a file.
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

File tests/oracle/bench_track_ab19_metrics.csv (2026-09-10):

metric | value
rms_err_deg | 4.361613372292228
peak_err_deg | 9.090662089393883
mae_err_deg | 3.2798529494340207
peak_tau_Nm | 16.004120587370423
pct_authority | 11.25465582796795
sat_pct | 0.0
peak_vel_rad_s | 5.055899819703143
peak_ref_vel_rad_s | 5.10772683377614
peak_power_W | 58.21357505829603
mean_abs_power_W | 12.485135982791574
ref_clamped_steps | 0
ankle_dev_deg | 0.2934172991916203
force_limit_Nm | 142.2
final_time_s | 1.2049999999999228
n_steps | 2410
rms_err_deg_after_50ms | 4.451034473978376
peak_err_deg_after_50ms | 9.090662089393883
lag_ms | 29.500000000000004
lag_pct_gc | 2.4481327800829877
rms_err_deg_lag_removed | 0.4333162512910977
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

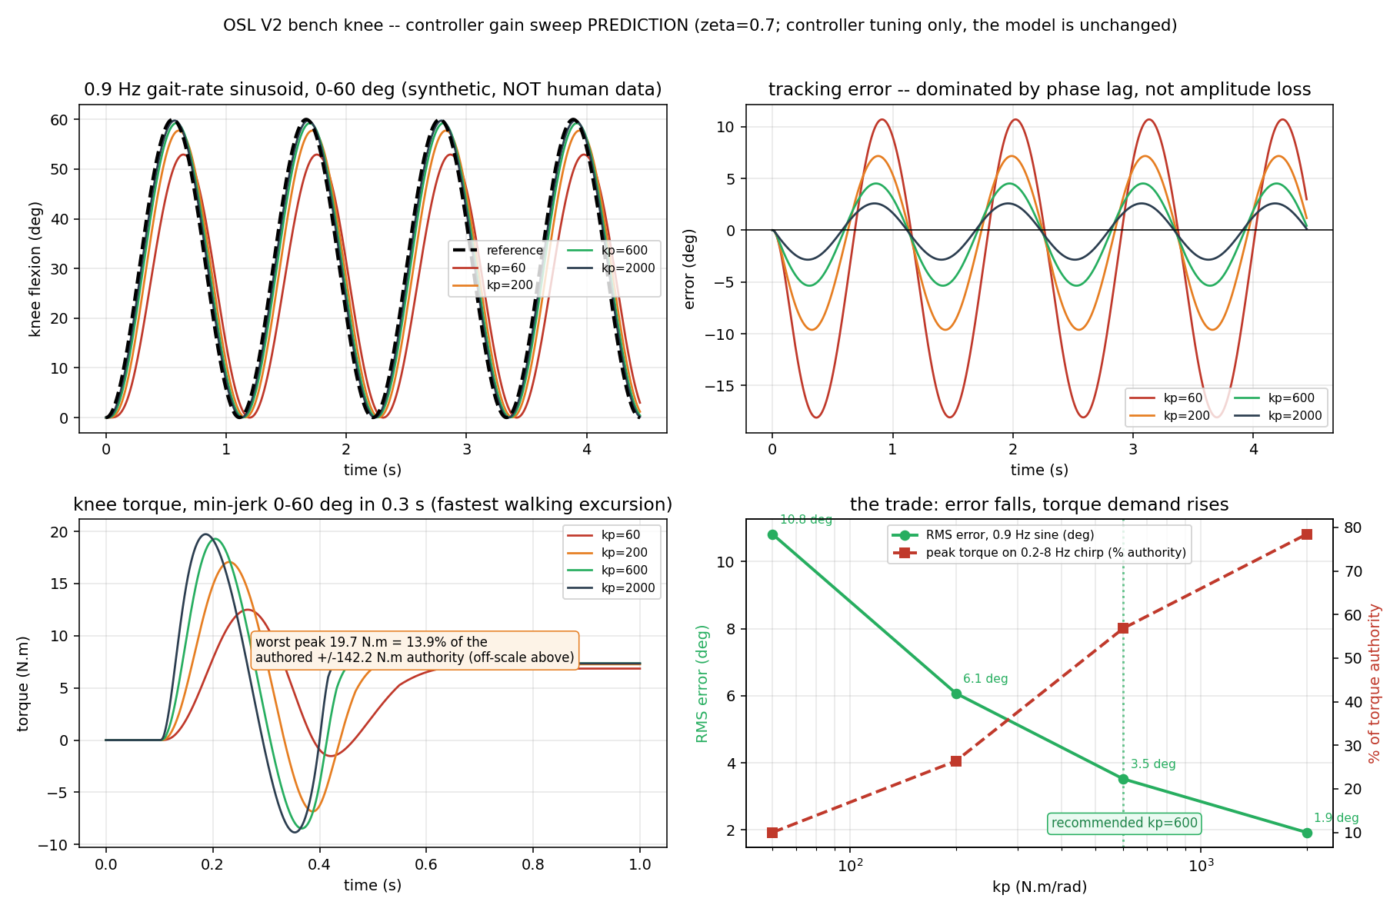
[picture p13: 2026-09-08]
experiments/gain_sweep_prediction.png

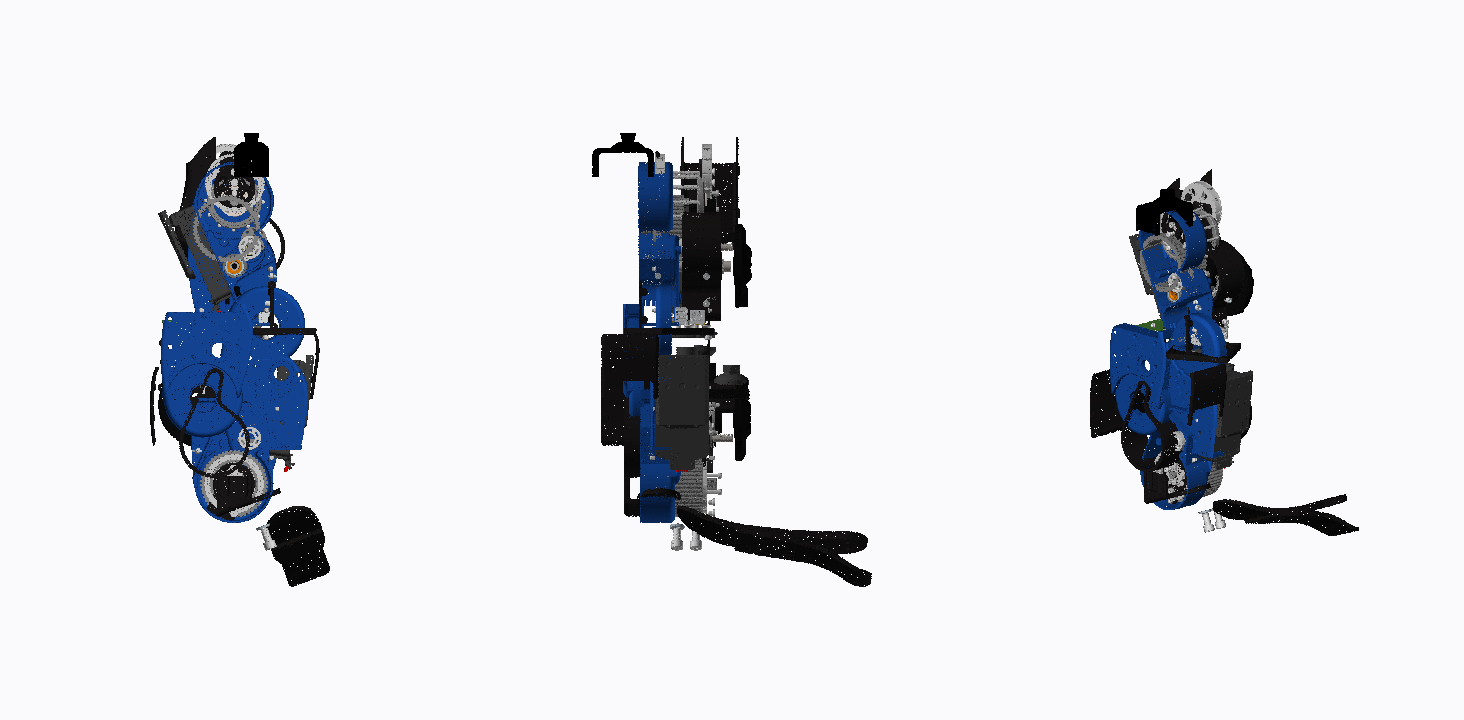
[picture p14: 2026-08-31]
build/verify/frames_A.png

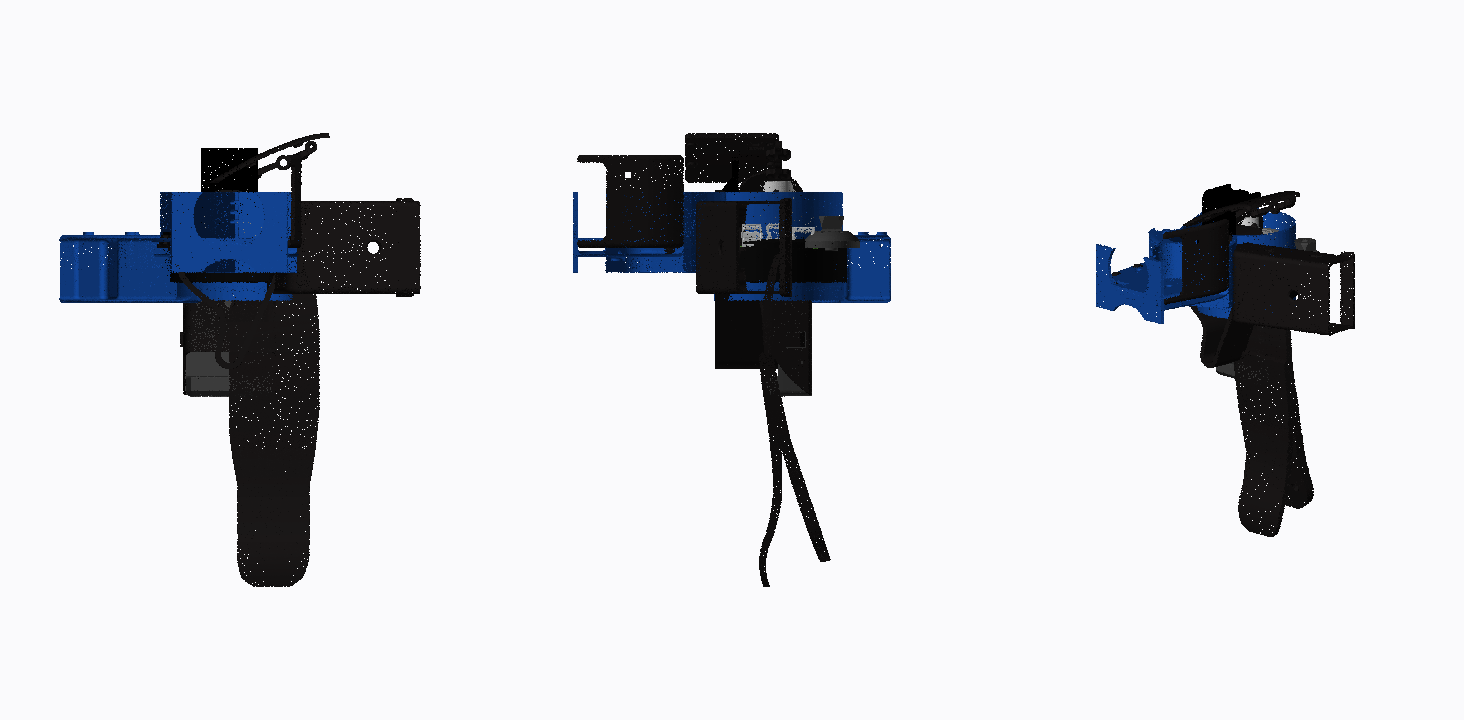
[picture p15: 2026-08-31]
build/verify/frames_B.png

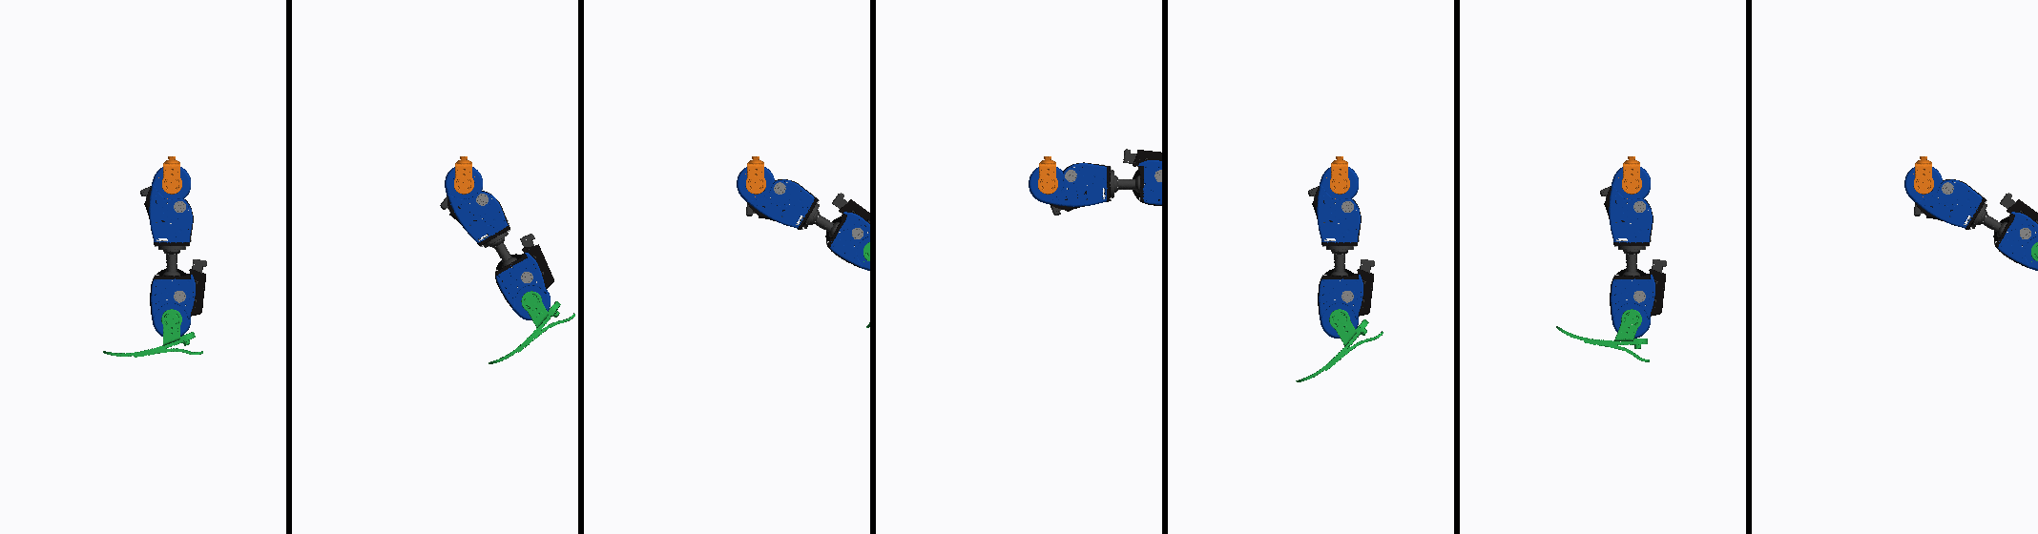
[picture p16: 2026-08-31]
build/verify/poses.png

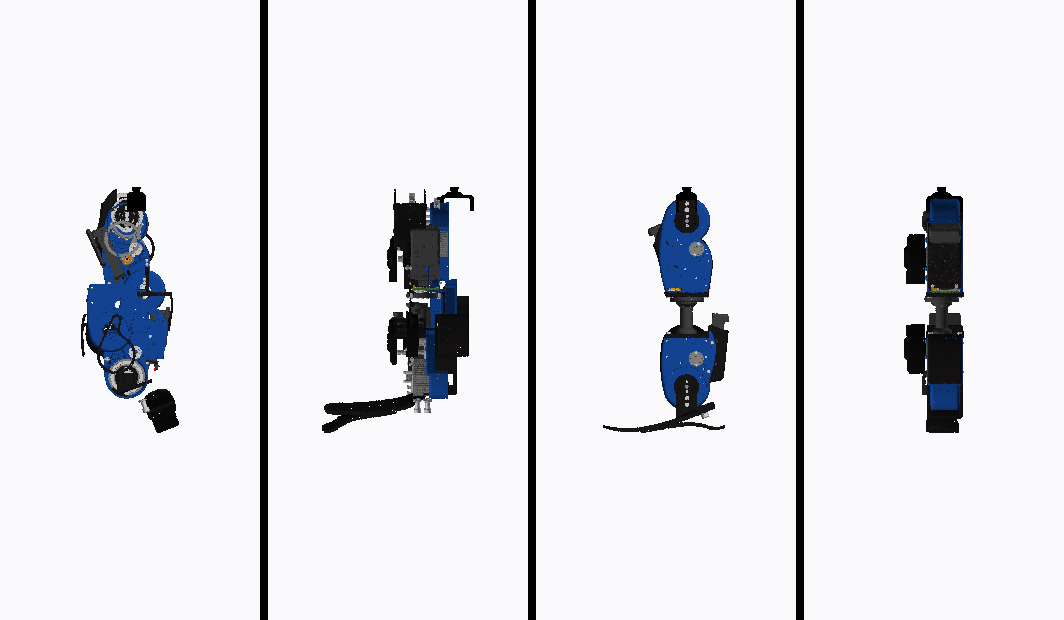
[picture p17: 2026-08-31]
build/verify/visorigin_AB.png

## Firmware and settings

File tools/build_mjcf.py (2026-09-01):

#!/usr/bin/env python3
"""
build_mjcf.py -- generate native MJCF for the OSL V2 straight from the
*untouched* Onshape export.

Why native MJCF instead of loading the URDF?  MuJoCo's URDF reader
eigen-decomposes every <inertial> block during parsing, before compiler
options apply, so `inertiafromgeom="true"` cannot rescue a bad tensor.  And
the export's inertials are not merely degenerate -- Onshape wrote it with no
materials assigned, so the total mass over all 682 links is 0.0148 kg, and 52
of the 657 inertial blocks have a non-positive eigenvalue (8 of those also
violate the triangle inequality) for a leg that really weighs 5.377 kg
(PUBLISHED_MASS below).  Every inertial in the export is therefore discarded
and mass is recovered from  mesh volume x assigned density  (see DENSITY_RULES
in oslcad.py), which lands at 4.9558 kg -- 0.42 kg light, and the export
contains no motors at all, which is very likely the whole of the difference.
See MOTOR_MASS.  build/mass_audit.csv lists every part.

Pipeline
--------
1. parse + forward-kinematically resolve the export            (oslcad.OslCad)
   -- including <visual><origin>, which 207 of the 682 links need
2. drop the 32 mesh-less Onshape phantom links
   (`parallel_*`, `planar_*`, `cylindrical_*`, `*_loop_closure`)
3. contract every `fixed` joint into rigid clusters (union-find)
4. assign each cluster to knee_prox / shank / foot, resolving the ones
   concentric with a hinge axis by the belt-drive rule below
5. re-verify the Ossur Variflex foot mate (_check_foot); nothing is repaired,
   the export's mate is correct
6. cull parts below CULL_VOLUME, lumping their mass into their segment
7. emit exact, guaranteed-valid inertials and two scenes

Nothing here edits the source URDF.

Usage:  python tools/build_mjcf.py [--report]
"""

from __future__ import annotations

import argparse
import collections
import json
import math
import os
import sys
import xml.etree.ElementTree as ET

import numpy as np

sys.path.insert(0, os.path.dirname(os.path.abspath(__file__)))
from oslcad import OslCad, density_for, mat_to_quat, rpy_to_mat  # noqa: E402

ROOT = os.path.dirname(os.path.dirname(os.path.abspath(__file__)))
URDF = os.path.join(ROOT, "osl_v2_0_assembly", "urdf", "osl_v2_0_assembly.urdf")
MESHES = os.path.join(ROOT, "osl_v2_0_assembly", "meshes")
MODELS = os.path.join(ROOT, "models")
MESHDIR_REL = "../osl_v2_0_assembly/meshes"

# ---------------------------------------------------------------------------
# Geometry constants measured from the CAD.  Every one of them is re-derived,
# with its evidence, by  python tools/cad_findings.py  -- whose output is what
# docs/CAD_FINDINGS.md contains.  If a number here and a number there disagree,
# the script is right.
# ---------------------------------------------------------------------------

# Knee and ankle hinge locations, both about world Y.  Established from
# concentric bearing / pulley clusters and cross-validated against the
# housing plate normals (which agree to 0.00 deg with each other and are
# 90.00 deg from the pylon).
KNEE_POS = np.array([0.00065, 0.0, 0.19311])
ANKLE_POS = np.array([0.00000, 0.0, -0.13873])

# +Z proximal, -Z distal, sagittal plane = world XZ.
#
# ANTERIOR IS -X.  Determined from the foot, which is the only unambiguous
# anatomical landmark in the assembly: the Variflex blade spans x = -0.1665 to
# +0.0756 while its mounting bolts sit at x ~ +0.035, so the long forefoot runs
# toward -X and the short heel toward +X.  (An earlier guess of +X, based on the
# Dephy battery bracket sitting at x ~ -0.052, was wrong -- batteries are not a
# reliable anterior/posterior cue.)  Both hinge-axis signs below happen to be
# unaffected by the correction.
ANTERIOR = np.array([-1.0, 0.0, 0.0])

# A rigid cluster whose centroid is this close to a hinge axis (measured in
# the sagittal plane) is that joint's bearing / output-pulley / gear-stop
# group.  In a belt-driven actuator the output pulley rotates *relative to
# the housing*, so it is rigidly part of the OTHER segment: the knee housing
# is shank-fixed, so knee-concentric clusters belong to the knee_prox; the ankle
# housing is shank-fixed, so ankle-concentric clusters belong to the foot.
AXIS_CLUSTER_RADIUS = 0.020

# Parts smaller than this are dropped from the model and their mass lumped
# into the segment (Goutham's choice: "cull tiny parts entirely").  0.10 cm^3
# keeps 217/650 links and 99.54 % of the total volume.
CULL_VOLUME = 0.10e-6  # m^3

# Mass of the physical OSL V2 knee-ankle build, from a published source.
#
# 5.377 kg is stated in Tan et al., "MyoAssist 0.1: MyoSuite for Dexterity and
# Agility in Bionic Humans", ICORR 2025, section IV-A, describing the mass they
# matched their myoOSL prosthesis model to.  They cite Best et al. 2024
# (IEEE/ASME T-Mech) and Azocar et al. 2018 (BioRob), and Elliott Rouse -- who
# runs the OSL project -- is a co-author, so this is as close to authoritative
# as a number gets without weighing the hardware.
#
# This REPLACES an earlier 3.0-4.5 kg range that was my own recollection with
# no source behind it.  That range made the model look 0.46 kg too heavy and
# pointed the finger at the density assignments.  Against the published figure
# the model is instead 0.42 kg too LIGHT, which is a different problem with a
# different and much more satisfying cause -- see MOTOR_MASS below.
PUBLISHED_MASS = 5.377  # kg

# Range the CAD-derived total should fall in.  It is deliberately BELOW
# PUBLISHED_MASS, because the export is missing both motors (MOTOR_MASS): two
# OSL-class brushless motors plausibly run 0.15-0.30 kg each, so a correct
# CAD-only total should land roughly 0.3-0.6 kg light.  The window is tight
# enough that a real density blunder still trips it.  validate_mjcf.py imports
# this so there is one number in the repo rather than three that disagree.
MASS_RANGE = (4.70, 5.20)  # kg, CAD-derived total, motors excluded

# THE MOTORS ARE NOT IN THE ONSHAPE EXPORT.
#
# All 260 distinct mesh files were searched for anything motor-like.  The only
# hit is p_b0004_motorCoupling.stl at 8.8 g, present twice -- the couplings
# that bolt TO the motors.  There is no rotor, no stator, no gearbox and no
# Dephy actuator body anywhere in the export.  The heaviest parts are housings,
# batteries, the load cell and the foot; nothing is a motor.
#
# That accounts for the gap: PUBLISHED_MASS - 4.9558 = 0.4212 kg, which is
# 0.2106 kg per motor if the two are identical -- the right order for a
# brushless motor of this class.
#
# DEFAULT IS ZERO, ON PURPOSE.  Two reasons.  First, this repo's claim is that
# it contains no invented geometry or mass, and a motor inferred from a
# residual is exactly that.  Second and more important, deriving the motor mass
# from (published total - our total) and then citing the agreement as
# validation would be circular.  The 4.9558 kg figure has to stand on its own.
#
# To include the motors, set this to a MEASURED per-motor mass -- weigh one
# when the hardware arrives, or take it from the Dephy actuator datasheet.  The
# mass is added as a point mass at each p_b0004_motorCoupling centroid, both of
# which are shank-fixed (consistent with the belt-drive rule: the housings are
# shank-fixed, so the motors are too).  Rotor inertia, once known, is also what
# JOINTS[*]["armature"] should be derived from, via the 50/11 belt ratio.
MOTOR_MASS = 0.0  # kg per motor; 0 = CAD only
MOTOR_LINKS = ("p_b0004_motorcoupling", "p_b0004_motorcoupling_1")

# The Variflex foot and its adapter.  NOTE: an earlier pass concluded that
# revolute_30 (adapter -> foot) was corrupt and reconstructed the foot from
# named anatomical constants.  That was wrong: the diagnosis had been made
# with the mesh placed by link pose alone, ignoring <visual><origin>.  Once
# the visual origin is folded in (see visual_origins() below) the export's own
# mate is correct -- the sole is within 2.18 deg of level, the foot's length
# axis is 89.73 deg from the ankle axis, and the M8 bolts sit centred inside
# the adapter.  Nothing about the foot is reconstructed; the residual 2.18 deg
# is the build's real alignment tilt and is deliberately preserved.
FOOT_LINK = "z_lowprofilevariflexfoot_ossur_vlpe5xx0"
ADAPTER_LINK = "p_b2015_proxpyramidvariflex"

# --- collision geometry ----------------------------------------------------
#
# WHAT WAS HERE BEFORE, AND WHY IT WAS NOT ENOUGH.  The ground scene used to
# carry exactly one collision geom: a 6 mm-thick box hugging the sole, tilted to
# follow the foot's alignment.  Two things were wrong with it.
#
#   1. The box was flat and the sole is not.  Fitted to the blade's bounding
#      box, its lower face sat 4.6 mm BELOW the blade mesh, so the leg stood on
#      a surface that does not exist, and every roll-over property of a carbon
#      blade -- toe spring, heel radius, the fact that the contact point
#      migrates forward through stance -- was thrown away.
#   2. Nothing above the ankle could collide at all.  Change the ankle angle
#      under control and the shank or the knee module simply passes through the
#      floor.  That is the "leg goes underground" symptom exactly.
#
# WHAT IS HERE NOW.  The sole is a `type="mesh"` geom on the blade's own mesh,
# at the same pose as its visual geom.  MuJoCo collides meshes by their convex
# hull, and for this part the hull is nearly the part: the toe spring and the
# heel roll-off are both convex, so they survive exactly.  The one thing the
# hull does not reproduce is the arch -- the Variflex LP is two overlapping
# blades, an upper forefoot blade and a lower J-shaped heel blade, and the hull
# bridges the 14 mm gap between their contact points.  That is deliberate and
# arguably closer to the truth than the raw surface: under body weight the real
# blade flattens toward the chord, and a rigid model cannot flatten, so the
# chord is the better stand-in for the loaded shape.  It is still an
# approximation and it is the first thing to revisit if roll-over shape starts
# to matter.  Zero invented numbers either way -- the geometry is the CAD's.
#
# Above the ankle the job is different.  The shank and knee_prox do not need a
# faithful contact shape; they need to not be able to reach the floor.  So each
# gets axis-aligned BOUNDING BOXES, one per real module, and the code says
# bounding rather than shape on purpose: measured fill fractions are 22.2 %
# (knee module), 11.2 % (mid/pylon), 19.8 % (ankle module) and 20.7 % (knee_prox).
# Those boxes enclose a lot of air.  Two alternatives were measured and dropped:
#
#   * capsules, fitted by PCA to each module -- rejected with numbers.  The knee
#     module wanted r = 81 mm and len = 174 mm on a part whose bounding box is
#     128 x 119 x 204 mm, with 1.0 % of vertices still 14.8 mm outside.  These
#     modules are blocky, not elongated; a capsule is the wrong primitive and
#     the fit says so.
#   * slicing each module into 25 mm z-slabs and boxing each slab -- 23 geoms
#     instead of 4 and fill only rises 22 % -> 30 %, because the looseness is in
#     x/y (batteries hang off one side), not in z.  Not worth 19 extra geoms.
#
# The boxes are validated for sufficiency rather than assumed, and by code
# rather than by this comment: OslModel.sweep_clearance sweeps the whole joint
# envelope (knee -5..120 deg x ankle -30..+20 deg, 26 x 26 poses) and reports the
# lowest point of any visual mesh against the lowest collision geom.  Over all
# 216 visual meshes the worst case is 5.9 mm clear, and over the 46 that no box
# contains -- the foot's non-blade hardware, since the foot's only collision geom
# is the blade mesh -- it is 23.6 mm clear, worst case at knee = -5 deg,
# ankle = -2 deg, where an M8 socket head hanging off the blade mount is the
# binding part.  The two figures differ because a part inside a box on its own
# body can never get below that box, so its clearance only measures how close a
# rotating box corner passes to it; the unboxed figure is the one with
# information in it.  Either way no mesh can reach the floor before a collision
# geom does.  Both numbers go into the sidecar and scripts/check_model.py
# re-derives them from MuJoCo's own forward kinematics, so neither the CAD-side
# sweep nor the MuJoCo-side one is taken on trust.
#
# Module membership is taken from the CAD's own named housings rather than from
# a z threshold someone picked: a shank part belongs to the knee module or the
# ankle module according to which housing's z-span its own z-span overlaps more,
# and to the mid/pylon group if it overlaps neither.  The two housings do not
# overlap (knee 0.0471..0.2389, ankle -0.1845..-0.0283, a 75.4 mm gap), so the
# rule is unambiguous, and the 11 parts that land in the middle are exactly the
# ones you would name by hand: the pylon, the load cell, the pyramid and their
# M5 bolts.
MODULE_SEEDS = {
    "knee_module": ("p_b1018_housingkneeright", "p_b1018_housingkneeleft"),
    "ankle_module": ("p_b2013_housingankleright", "p_b2013_housingankleleft"),
}

# Spawn clearance for the ground scene: the whole leg is lifted so the lowest
# collidable point starts this far above the floor.  Small enough not to matter,
# large enough that the first contact is resolved by the solver rather than by
# an initial penetration.
SPAWN_CLEARANCE = 0.002  # m

# --- joint / actuator parameters ------------------------------------------
# Positive = flexion, matching the OSL convention.  Knee flexion swings the
# shank posteriorly, so the knee axis is -Y; ankle dorsiflexion lifts the toe,
# so the ankle axis is +Y.
#
# PEAK TORQUES are published, not guessed: knee 142.2 N.m and ankle 168.2 N.m,
# from Tan et al. 2025 (see PUBLISHED_MASS), who matched their myoOSL actuators
# to them.  These replace an invented +-100 N.m that was in this file purely so
# the actuators had *some* limit.  The ankle being stronger than the knee looks
# wrong at first glance and is not -- the ankle module carries the higher belt
# reduction because push-off is the more demanding task.
#
# RANGES OF MOTION disagree with that same paper and OURS ARE KEPT.  The paper
# lists knee 0-120 deg and ankle -30 to +30 deg; the CAD gives knee -5 to +120
# and ankle -30 to +20.  Both differences are real and ours is better sourced:
# the -5 deg of knee hyperextension is the physical hard stop in this assembly,
# and the +20 deg dorsiflexion limit is where this particular Variflex adapter
# stack runs out of travel.  A paper describing "the OSL v2" in general is a
# weaker authority on our specific export than the export is.  Revisit only if
# the hardware measures otherwise.
JOINTS = {
    "knee": dict(
        axis=(0.0, -1.0, 0.0),
        range=(math.radians(-5.0), math.radians(120.0)),
        damping=0.30,
        armature=0.010,
        frictionloss=0.40,
        kp=60.0,
        forcerange=(-142.2, 142.2),  # published peak, Tan et al. 2025
    ),
    "ankle": dict(
        axis=(0.0, 1.0, 0.0),
        range=(math.radians(-30.0), math.radians(20.0)),
        damping=0.25,
        armature=0.008,
        frictionloss=0.30,
        kp=60.0,
        forcerange=(-168.2, 168.2),  # published peak, Tan et al. 2025
    ),
}
# NOTE on what is and is not identified above.  `forcerange` and `range` now
# have sources (published peak torque, CAD hard stops).  `damping`, `armature`,
# `frictionloss` and `kp` do NOT -- they are plausible placeholders, collected
# here so they can be fitted against bench data in one place.  `kp=60` in
# particular is far too soft to hold a stance limb and is expected to change as
# soon as the model carries load; see the walk scene.

SEGMENTS = ("knee_prox", "shank", "foot")

# ===========================================================================
# PHASE 2 -- HUMAN SCAFFOLD FOR THE `walk` SCENE.
#
# READ THIS BEFORE TRUSTING ANY NUMBER BELOW.  Everything above is measured
# from the CAD and is the point of this repo.  Everything in THIS block is the
# opposite: the pelvis, the residual (amputated) thigh, the socket and the
# intact contralateral leg are NOT in the Onshape export, because they are
# anatomy, not the device.  They exist only so the CAD-derived leg has a hip to
# hang from, a socket interface to load, and a second leg and a floor to walk
# against -- the "realistic, walkable" model the professor asked for.
#
# So these are PRIMITIVES (capsules / boxes) with PLACEHOLDER masses and
# lengths, and they are flagged as such at runtime (see OslModel._emit_walk,
# which appends a note to every build).  This is deliberately NOT the "generic
# capsule model" the ground rules forbid: that rule protects the DEVICE from
# being replaced by a rod, and the device here is still the exact CAD mesh
# tree.  The capsules are only the human it bolts onto, and the intent is to
# replace them -- or reconcile them -- with the myoOSL musculoskeletal model
# (MyoAssist / myo_sim) once the two are cross-checked.  Until then, treat
# every constant here as a round number chosen to be plausible, not as data.
#
# Anthropometry is 50th-percentile male (body mass ~75 kg), segment fractions
# after Winter, "Biomechanics and Motor Control of Human Movement" (2009), with
# the transfemoral residual limb taken at roughly a 50 % level.  None of it is
# fitted to this patient or this build.
# ===========================================================================
BODY_MASS = 75.0            # kg, reference 50th-pct male (Winter 2009)

# -- suspended pelvis (the "gantry"): welded to the world for now; a prescribed
#    trajectory will drive it later, so no balance controller is needed yet.
PELVIS_MASS = 10.0          # kg, pelvis + lumped lower-HAT the gantry carries
PELVIS_HALF = (0.070, 0.110, 0.060)   # m, pelvis box half-extents (x, y, z)
HIP_HALF_WIDTH = 0.090      # m, each hip offset laterally from pelvis midline
# device (residual) leg on +Y, intact leg on -Y.

# -- residual thigh (amputated limb the socket grips)
RES_THIGH_MASS = 3.5        # kg, transfemoral residual limb, ~50 % level
RES_THIGH_LEN = 0.20        # m, residual femur length (~1/2 of a ~0.40 m femur)
RES_THIGH_RADIUS = 0.065    # m

# -- socket + pyramid adapter: the compliant interface between limb and device.
#    FOUR PASSIVE DOFs, each a spring-damper toward 0 (no actuator): axial
#    piston (limb sinks into the socket under load) plus flexion, ab/adduction
#    and internal/external rotation of the socket on the residuum.  The
#    stiffnesses and dampings are UNFITTED -- placeholders in one place so bench
#    data can calibrate them later, exactly like JOINTS[*]['kp'].
SOCKET_MASS = 0.6           # kg, socket + liner + pyramid hardware
SOCKET_LEN = 0.06           # m, socket depth below the residual limb
SOCKET_RADIUS = 0.060       # m
SOCKET_DOF = (
    # (name, type, axis, range, stiffness, damping)  -- axis in socket frame,
    # z = limb long axis, x = anterior/posterior, y = medio/lateral.
    ("socket_piston", "slide", (0.0, 0.0, 1.0), (-0.020, 0.020), 80000.0, 800.0),
    ("socket_flex",   "hinge", (0.0, 1.0, 0.0),
     (math.radians(-10.0), math.radians(10.0)), 40.0, 2.0),
    ("socket_abad",   "hinge", (1.0, 0.0, 0.0),
     (math.radians(-10.0), math.radians(10.0)), 40.0, 2.0),
    ("socket_rot",    "hinge", (0.0, 0.0, 1.0),
     (math.radians(-15.0), math.radians(15.0)), 25.0, 1.5),
)

# -- hip joints (pelvis -> thigh).  Single sagittal flexion/extension hinge for
#    now, the DOF a walking trajectory drives; ab/ad and rotation can be added.
#    Positive = flexion (thigh swings anterior, i.e. toward -X): a +Y hinge on a
#    down-pointing (-Z) thigh moves the distal end toward -X, so axis = +Y.
HIP = dict(
    axis=(0.0, 1.0, 0.0),
    range=(math.radians(-20.0), math.radians(120.0)),
    damping=1.0, armature=0.0, frictionloss=0.0, kp=150.0,
    forcerange=(-200.0, 200.0),   # placeholder hip torque limit
)

# -- contralateral (intact) leg: ONE lumped rigid body (thigh+shank+foot),
#    hip-hinged so it can swing, with a box foot that contacts the floor.  Mass
#    is the whole-leg fraction 0.161 * BODY_MASS.
CONTRA_MASS = round(0.161 * BODY_MASS, 3)   # kg (~12.08)
CONTRA_RADIUS = 0.060       # m, lumped-leg capsule radius
CONTRA_FOOT_HALF = (0.110, 0.045, 0.030)    # m, foot box half-extents (x,y,z)
CONTRA_FOOT_XOFF = -0.030   # m, foot centred slightly anterior (-X)
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

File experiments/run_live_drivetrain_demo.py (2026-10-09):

#!/usr/bin/env python3
"""
run_live_drivetrain_demo.py -- THE OPTION-C LIVE DEMO.  Entry point, not implementation.

    OPTION C -- PAPER-DERIVED ACTUATOR + COMPLIANT BELT
    SIMULATION ONLY -- NOT HARDWARE VALIDATION

WHAT IT IS
    `experiments/run_bench_ab19_drivetrain.py`'s Case B, shown while it happens: a MuJoCo
    window with the CAD OSL V2 bench moving, and a second window plotting the actuator
    and belt signals as they are produced.

WHAT IS NEW HERE, EXHAUSTIVELY
    A camera, a frame rate, wall-clock pacing, keyboard control, and drawing.  That is
    the whole list.  There is NO second physics or control implementation in this file:

      * the control law is `oslbench.drivetrain_sim.PDCurrentSource` -- the same object
        the quantitative run uses.  The PD equation is NOT restated here; grep this file
        for `kp` and you will find it passed, never multiplied.
      * the plant is `oslbench.drivetrain_sim.DrivetrainBenchSimulation.step()` -- the
        same call, with the same `DrivetrainLayer` carrying Best et al.'s equations.
      * the servo-disconnect is the same `disconnect_servo=True` mechanism, and its
        result is verified before the window opens rather than assumed.
      * the gains are imported from `oslbench.controller` (KP, KD).  This file cannot
        change them and `--kp`/`--kv` are deliberately NOT offered.
      * the reference is the same resampled AB19 cycle.

    `--speed` changes how many 0.5 ms physics steps are packed into one rendered frame
    and how long the loop sleeps.  It NEVER changes dt, which stays at the model's
    authored 0.5 ms at every playback rate.

WHAT THE SECOND WINDOW IS AND IS NOT
    A CONSUMER of state.  `oslbench/drivetrain_dashboard.py` holds no model, takes no
    timestep and computes no torque or current; it is handed the numbers the step just
    produced and draws them, in the browser's process.  It cannot write a command.  Close
    it and the physics is identical.

WHY THE TORQUE PANEL HAS TWO SCALES, AND THE ANGLE PANEL ONE
    `tau_j` (joint side) and `tau_a` (actuator side) differ by n_t = 4.61 and are never
    drawn on one axis -- plot 4 gives the current its own right-hand scale for the same
    reason.  Plot 2 is the deliberate exception: `theta_a/n_t` has already been referred
    THROUGH the transmission, so it and `theta_j` are the same physical quantity measured
    at the two ends of the belt, and the gap between them IS the deflection.  A rigid
    transmission would draw a single line there.

USAGE (Windows PowerShell)
    .venv\\Scripts\\python.exe experiments\\run_live_drivetrain_demo.py
    .venv\\Scripts\\python.exe experiments\\run_live_drivetrain_demo.py --speed 0.25
    .venv\\Scripts\\python.exe experiments\\run_live_drivetrain_demo.py --speed 1.0
    .venv\\Scripts\\python.exe experiments\\run_live_drivetrain_demo.py --dashboard terminal
    .venv\\Scripts\\python.exe experiments\\run_live_drivetrain_demo.py --headless --max-cycles 1

    Keys, in either window:  Space pause/resume   R restart the cycle   Esc exit

WHAT IT WRITES
    Nothing, by default.  No CSV, no PNG, no model.  `--dump-html` writes one standalone
    copy of the dashboard page for inspection and is the only output path in the file.
"""

from __future__ import annotations

import argparse
import contextlib
import io
import math
import os
import sys
import time

import numpy as np

ROOT = os.path.dirname(os.path.dirname(os.path.abspath(__file__)))
if ROOT not in sys.path:
    sys.path.insert(0, ROOT)

from oslbench import drivetrain_dashboard as ddash                          # noqa: E402
from oslbench import viewer as vw                                           # noqa: E402
from oslbench.controller import KD, KP, PDController                        # noqa: E402
from oslbench.drivetrain import PAPER                                       # noqa: E402
from oslbench.drivetrain_sim import (DrivetrainBenchSimulation,             # noqa: E402
                                     DrivetrainLayer, PDCurrentSource)
from oslbench.model import load_bench_model                                 # noqa: E402
from oslbench.reference import (DEFAULT_REFERENCE_CSV, STANCE_END,          # noqa: E402
                                SUBJECT, TRIAL, audit_reference,
                                load_reference, resample_reference)

BANNER = ddash.BANNER
DISCLAIMER = ddash.DISCLAIMER
SPEEDS = (0.25, 0.5, 1.0)
FIT_EDGE_RAD = 0.055        # ASSUMED: Best et al. Fig. 3 abscissa; past it the belt law
#                             is extrapolation of their regression, not their data
K_T_JOINT = PAPER.n_t * PAPER.k_t * PAPER.n_a        # 4.597092 N.m/A, PAPER-DERIVED
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

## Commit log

2026-08-31 Initial OSL V2 MuJoCo simulation
    [BA30_P002_V04_CHASSIS_STEP.stl, BA30_P003_V04_REARCOV_STEP.stl, BA30_P004_V04_FRONTCOV_STEP.stl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]
2026-09-01 cad findings
2026-09-01 ground model update
2026-09-10 gait cycle values
    [bench_track_ab19.csv, bench_track_ab19_metrics.csv]
2026-10-08 drivetrain diagnosis report
2026-10-08 drivetrain diagnosis script
2026-10-08 drivetrain actuator dynamics model
2026-10-08 drivetrain check script
2026-10-08 gait tracking with actuator dynamics
2026-10-10 drivetrain dashboard
2026-10-10 drivetrain tests
2026-10-17 ankle current sensitivity experiment
2026-10-17 current control ankle experiment
2026-10-18 current controlled experiment
2026-10-18 debugginf high torque, feedback location experiment
2026-10-18 Implement Phase 6F-B IMU telemetry pipeline
2026-10-20 current loop sensitivity experiment
2026-10-20 joint current control test
2026-10-21 drivetrain parameters doc
2026-10-22 drivetrain instability and diagnosis
2026-10-27 architectur and current controll tests
2026-10-28 compliance belt bench model update
2026-10-28 drivetrain update
2026-10-30 project briefing and research flow
2026-10-31 current controll update
2026-11-02 replay jitter fixture
2026-11-07 cad to mujoco pipeline
